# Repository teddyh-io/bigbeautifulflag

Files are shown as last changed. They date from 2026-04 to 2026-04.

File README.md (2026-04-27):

# Truth Social Flagpole

A physical installation that raises an American flag when
[@realDonaldTrump](https://truthsocial.com/@realDonaldTrump) has gone too
long without posting on Truth Social, and lowers it again every time he posts.

## Behaviour

- Poll Truth Social every minute (configurable).
- Flag rises 10% for every 30 minutes of silence, capping at 100%
  (i.e. fully raised after 5 h 30 m of no new posts).
- Any new post drops the flag back to 0%.
- A 64x32 RGB matrix scrolls the body of the latest post.
- When a new post is detected the matrix flashes a "NEW TRUTH" alert
  (two frames alternating every 200 ms for 5 s) before the new body
  scrolls in.
- Truths with attached media are described via OpenAI's vision API
  (`gpt-4o-mini` by default) and the description is appended after the
  body text (or shown by itself if the truth has no caption). Images
  produce an `Image of …` line; videos produce a `Video of …` line
  generated from the preview thumbnail (or the literal `[Video]` if the
  thumbnail is uninformative). Disabled when `OPENAI_API_KEY` isn't set.
- One HW-069 7-seg displays the current flag % and another counts down the
  seconds until the next 10% step.

## Repo layout

```
arduino/
  flagpole/
    flagpole.ino       # Uno sketch (motor + 2x TM1637)

pi/
  flagpole.py          # main systemd service
  calibrate.py         # standalone interactive calibration over SSH
  dev.py               # fake-post dev / demo mode (no Truth Social)
  matrix.py            # Piomatter + tom-thumb BDF scroller
  arduino.py           # serial protocol wrapper for the Uno
  truth.py             # polling + percent/countdown math
  vision.py            # OpenAI gpt-4o-mini wrapper for caption-less truths
  fonts/
    tom-thumb.bdf      # MIT-licensed 4x6 pixel font
  systemd/
    flagpole.service   # systemd unit (points at /home/teddyh/bigbeautifulflag/pi)
  requirements.txt
  .env.example

TWEET/
  FRAME1.png           # "NEW TRUTH" alert, frame 1 (64x32 RGB)
  FRAME2.png           # "NEW TRUTH" alert, frame 2 (64x32 RGB)
  FRAMES.psd           # Photoshop source for the alert frames

Pulley 3D Print/       # mechanical assets (STL/SLDPRT/SCAD)
README.md
.gitignore
```

Everything above is tracked in git except what `.gitignore` excludes:
`.env` (secrets), `__pycache__/`, `bbf-venv/`, the PIL cache built from the
BDF font on first run, and editor/OS cruft.

## Hardware

```
                                   +-------------------+
                                   |   64x32 RGB LED   |
                                   |   Matrix (HUB75)  |
                                   +---------+---------+
                                             |
                                   +---------+---------+
                                   |  Adafruit RGB     |
                                   |  Matrix Bonnet    |
                                   +---------+---------+
                                             |
                                   +---------+---------+
                                   |   Raspberry Pi 5  |
                                   +---------+---------+
                                             |  USB (serial)
                                             |
                                   +---------+---------+
                                   |   Arduino Uno     |
                                   +----+----+----+----+
                                        |    |    |
                                 H-bridge   TM1637 TM1637
                                        |    |    |
                                     Motor  Seg1  Seg2
                                            (flag %) (countdown)
```

### Arduino Uno pin map

See [arduino/flagpole/flagpole.ino](arduino/flagpole/flagpole.ino).

| Pin | Role |
| --- | --- |
| 9 | Motor H-bridge IN1 (PWM) |
| 10  | Motor H-bridge IN2 (PWM) |
| 2 | Seg1 (HW-069 flag %) CLK |
| 3 | Seg1 (HW-069 flag %) DIO |
| 4 | Seg2 (HW-069 countdown) CLK |
| 5 | Seg2 (HW-069 countdown) DIO |

## Arduino firmware (`arduino/`)

1. Install the [TM1637](https://github.com/avishorp/TM1637) library by
   Avishay Orpaz via the Arduino IDE Library Manager.
2. Open `arduino/flagpole/flagpole.ino`, select the Uno + its serial port,
   and upload.
3. The firmware keeps both 7-seg modules showing dashes until the Pi sends
   its first `P` / `T` command.

Calibration data lives in the Uno's EEPROM so it survives reboots and
firmware re-flashes (EEPROM layout is preserved from the original sketch).

## Pi setup (`pi/`)

Target: Raspberry Pi 5 running Raspberry Pi OS Bookworm 64-bit.

This repo is expected to be cloned at `/home/teddyh/bigbeautifulflag/` with
a virtualenv named `bbf-venv/` inside the `pi/` subfolder. If you put it
somewhere else (or name the venv differently), edit
[`pi/systemd/flagpole.service`](pi/systemd/flagpole.service) to match before
installing the service unit.

1. Clone this repo to `/home/teddyh/bigbeautifulflag` (so the Python code
   lives at `/home/teddyh/bigbeautifulflag/pi`).
2. Create the virtualenv **inside `pi/`** and install deps:

   ```bash
   cd ~/bigbeautifulflag/pi
   python3 -m venv bbf-venv
   bbf-venv/bin/pip install -r requirements.txt
   ```

   Piomatter on Pi 5 is a separate wheel; if `pip` can't find it, follow the
   [Adafruit Pi 5 Piomatter guide](https://learn.adafruit.com/rgb-matrix-panels-with-raspberry-pi-5).

3. Wire the Adafruit RGB Matrix Bonnet onto the Pi's 40-pin header and plug
   in the 64x32 HUB75 panel. Power the panel from its own 5V supply.
4. Plug the Arduino Uno into the Pi over USB (typically appears as
   `/dev/ttyACM0`).

## Calibration

Run this once to set the motor's LOW/HIGH endpoints. The Uno persists the
result in EEPROM, so you only redo it after mechanical changes.

```bash
# First run (before the service is installed) — nothing to stop.
cd ~/bigbeautifulflag/pi
bbf-venv/bin/python calibrate.py --port /dev/ttyACM0
```

After the systemd unit is installed, the service owns the serial port
exclusively, so stop it first and start it again when done:

```bash
sudo systemctl stop flagpole.service
cd ~/bigbeautifulflag/pi
bbf-venv/bin/python calibrate.py --port /dev/ttyACM0
sudo systemctl start flagpole.service
```

Keys:

| Key | Action |
| --- | --- |
| ↑ / ↓ | Fine jog (100 ms) |
| W / S | Coarse jog (1 s) |
| L | Mark the LOW endpoint (0%) |
| H | Mark the HIGH endpoint (100%) |
| R | Erase calibration from EEPROM |
| ? | Print Arduino status |
| 0–9 | Goto 0%, 10%, … 90% (once calibrated) |
| Q / Esc | Quit |

## Dev / demo mode

[`pi/dev.py`](pi/dev.py) runs the same motor + matrix + countdown pipeline
as the real service, but takes fake posts from stdin instead of polling
Truth Social. Useful for demoing the rig or debugging hardware without
waiting for @realdonaldtrump to post.

Like calibration, it owns the serial port and the matrix exclusively, so
stop the service first:

```bash
sudo systemctl stop flagpole.service
cd ~/bigbeautifulflag/pi
bbf-venv/bin/python dev.py
# ... type fake posts, age them, etc ...
sudo systemctl start flagpole.service
```

Stdin commands (also shown on startup):

| Input | Action |
| --- | --- |
| `<any text>` | Post `<any text>` at t=now. Flag drops to 0%, NEW TRUTH alert plays, body scrolls. |
| `post <body>` | Same as above, explicit form. |
| `<truth url>` | Pull a real post by URL (e.g. `https://truthsocial.com/@realDonaldTrump/116428386907912654`) and inject it as a fresh truth. Image-only posts get the same OpenAI vision description as the live service. |
| `age <dur>` | Rewind the last post by `<dur>` (e.g. `30s`, `45m`, `2h`, `5h30m`). Flag steps up accordingly within a second. |
| `state` / `?` | Print current percent, countdown, and age of the last post. |
| `help` / `h` | Reprint the banner. |
| `quit` / `q` | Exit (Ctrl-C or EOF also work). |

For typing fake bodies you don't need any credentials, but URL-paste and
the vision fallback both call the upstream APIs:

- Truth Social fetch uses `TRUTHSOCIAL_TOKEN` (or `TRUTHSOCIAL_USERNAME`
  + `TRUTHSOCIAL_PASSWORD`) — same env vars as the main service.
- The image-only vision fallback uses `OPENAI_API_KEY`. Without it,
  image-only posts just scroll `(no post)` instead of a description.

`dev.py` automatically loads `/etc/flagpole.env` (the same file
`flagpole.service` uses via `EnvironmentFile=`), so on the Pi the same
secrets you already configured for the systemd service are picked up
without any extra steps. A developer-local `.env` next to the script (or
anywhere up the cwd) takes precedence over `/etc/flagpole.env` if you
want to override anything for testing.

`ARDUINO_PORT` and `LOG_LEVEL` are honored as in the main service.

## systemd

Install the service so the flagpole starts on boot and restarts on crash.

```bash
cd ~/bigbeautifulflag

# Secrets (not tracked in git)
sudo cp pi/.env.example /etc/flagpole.env
sudo chmod 600 /etc/flagpole.env
sudo $EDITOR /etc/flagpole.env    # fill in TRUTHSOCIAL_USERNAME/PASSWORD

# Service unit
sudo cp pi/systemd/flagpole.service /etc/systemd/system/flagpole.service
sudo systemctl daemon-reload
sudo systemctl enable --now flagpole.service
journalctl -u flagpole.service -f
```

Useful service commands once it's installed:

```bash
sudo systemctl stop    flagpole.service   # stop (e.g. before calibrating)
sudo systemctl start   flagpole.service   # start again
sudo systemctl restart flagpole.service   # after editing code or the unit file
sudo systemctl status  flagpole.service   # quick health check
journalctl -u flagpole.service -n 100     # recent logs
```

The unit runs as `root` because Piomatter needs raw PIO access on the Pi 5.
If you prefer a non-root user, grant `cap_sys_rawio+ep` to the python
binary and change the `User=` line in `pi/systemd/flagpole.service`.

## Configuration

All configurable via environment variables (see [pi/.env.example](pi/.env.example)):

| Var | Default | Notes |
| --- | --- | --- |
| `ARDUINO_PORT` | `/dev/ttyACM0` | USB-serial device for the Uno |
| `TRUTH_HANDLE` | `realdonaldtrump` | Account to watch |
| `POLL_INTERVAL` | `60` | Seconds between Truth Social fetches |
| `TRUTHSOCIAL_USERNAME` | — (required) | Or set `TRUTHSOCIAL_TOKEN` instead |
| `TRUTHSOCIAL_PASSWORD` | — (required) | |
| `TRUTHSOCIAL_TOKEN` | — | Bearer token alternative |
| `OPENAI_API_KEY` | — | Optional. Enables vision description of caption-less image/video truths. |
| `OPENAI_MODEL` | `gpt-4o-mini` | Vision model used for the description call. |
| `LOG_LEVEL` | `INFO` | Any `logging` level name |

## Serial protocol (Pi → Uno)

9600 baud, newline-terminated, ASCII:

| Command | Meaning |
| --- | --- |
| `G<n>` | Move motor to n% (0–100) |
| `P<n>` | Show n on Seg1 flag display (`-1` blanks it) |
| `T<n>` | Start countdown of n seconds on Seg2 (`-1` blanks it)  |
| `U`/`D` | Fine jog up/down |
| `UU`/`DD` | Coarse jog up/down |
| `L`/`H` | Mark LOW / HIGH calibration endpoints |
| `R` | Reset calibration |
| `S` | Print `STATUS:` line |
| `?` | Print help |

The Uno's countdown ticks locally from the last `T` command, so the Pi only
needs to resend when the target changes (in practice, once per
`POLL_INTERVAL`).

## Font

[`pi/fonts/tom-thumb.bdf`](pi/fonts/tom-thumb.bdf) is the MIT-licensed
*Fixed4x6* (tom-thumb) bitmap font by Brian Swetland. It's converted to
PIL's native `.pil`/`.pbm` cache at first run (both gitignored); delete
those files if you ever replace the BDF.

## NEW TRUTH alert frames

[`TWEET/FRAME1.png`](TWEET/FRAME1.png) and
[`TWEET/FRAME2.png`](TWEET/FRAME2.png) are the two 64x32 RGB frames that
alternate every 200 ms for 5 seconds whenever a new post is detected, just
before the body scrolls in.  Replace them with any other pair of 64x32
PNGs to customise the alert — they're loaded once at service start. If the
files are missing the service still runs, it just skips the animation.

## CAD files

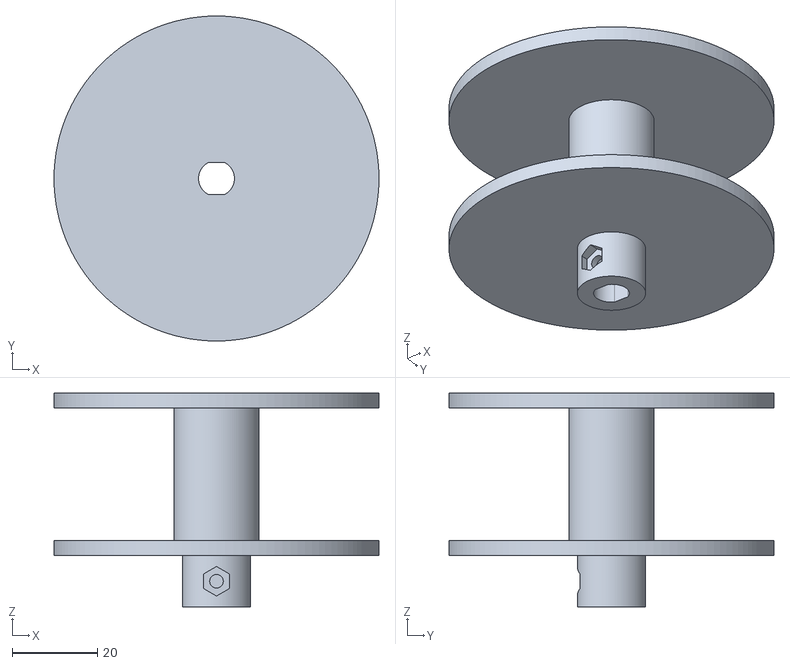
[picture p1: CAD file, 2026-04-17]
Pulley 3D Print/combined_pulley_v4.stl
76.2 x 76.2 x 50.1

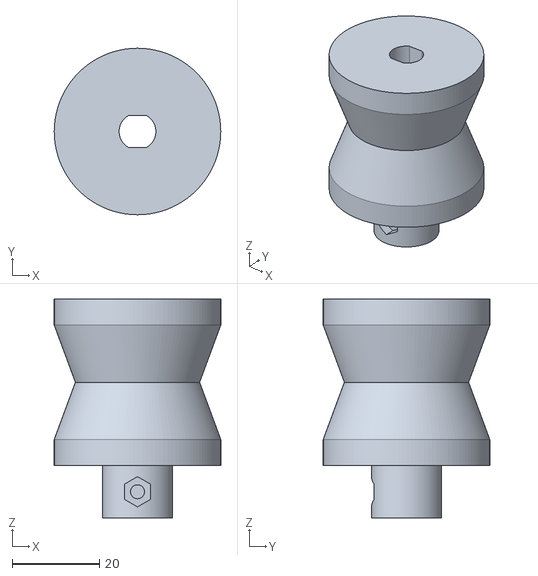
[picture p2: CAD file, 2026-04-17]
Pulley 3D Print/combined_pulley_adapter.stl
38.1 x 38.1 x 50.1

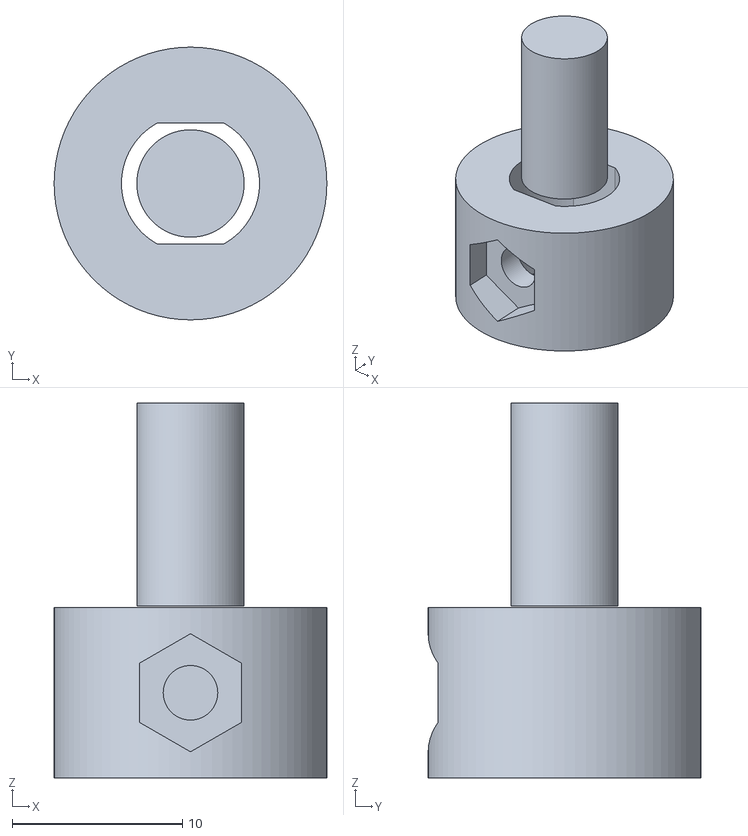
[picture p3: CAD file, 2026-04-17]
Pulley 3D Print/motor_pulley_adapter.stl
16.0 x 16.0 x 22.0

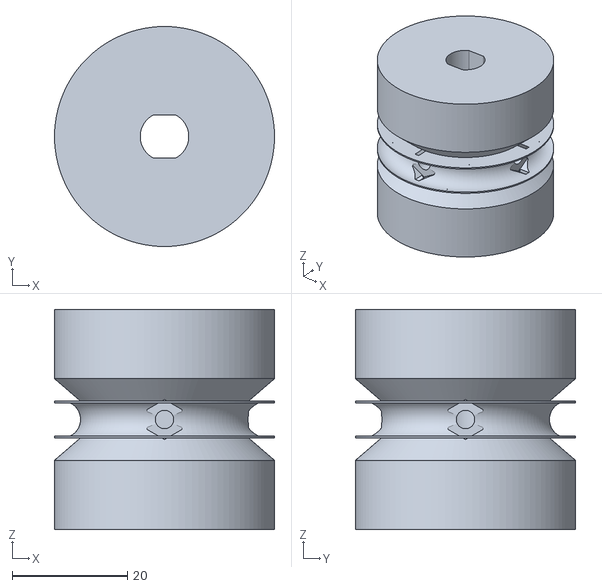
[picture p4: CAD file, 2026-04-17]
Pulley 3D Print/pulley_with_adapter.stl
38.1 x 38.1 x 38.1

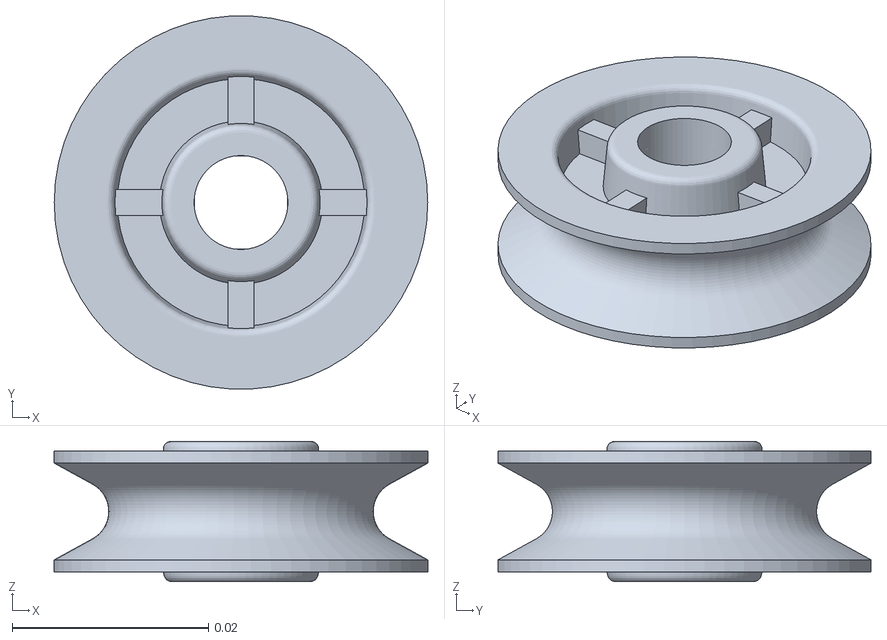
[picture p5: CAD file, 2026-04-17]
Pulley 3D Print/Pulley for Wire Rope 1-4 250 lbs Nylon.stl
0.0381 x 0.038 x 0.0143

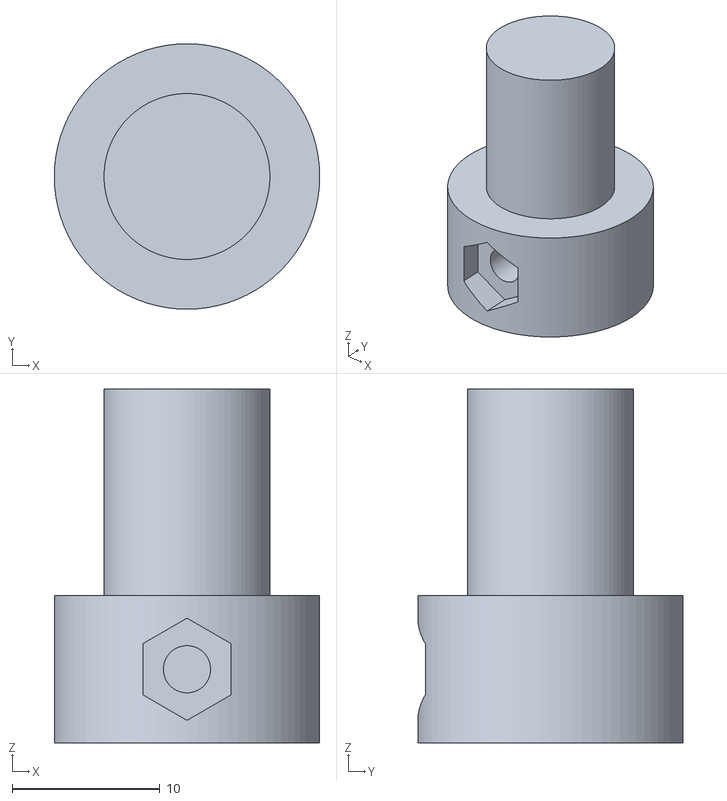
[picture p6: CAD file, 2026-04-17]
Pulley 3D Print/motor_pulley_adapterv3.stl
18.0 x 18.0 x 24.0

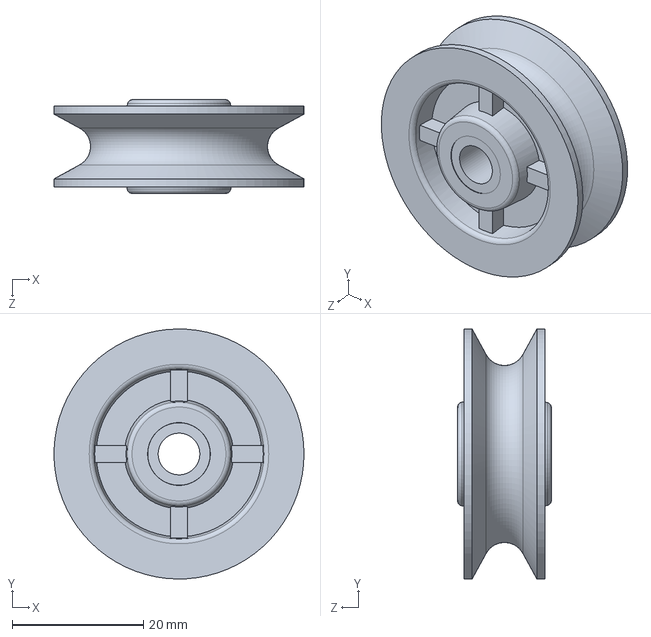
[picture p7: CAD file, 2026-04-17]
Pulley 3D Print/Pulley for Wire Rope 1-4 Rope Diameter 250 lbs Capacity Nylon.SLDPRT
38.1 x 38.1 x 14.3 mm

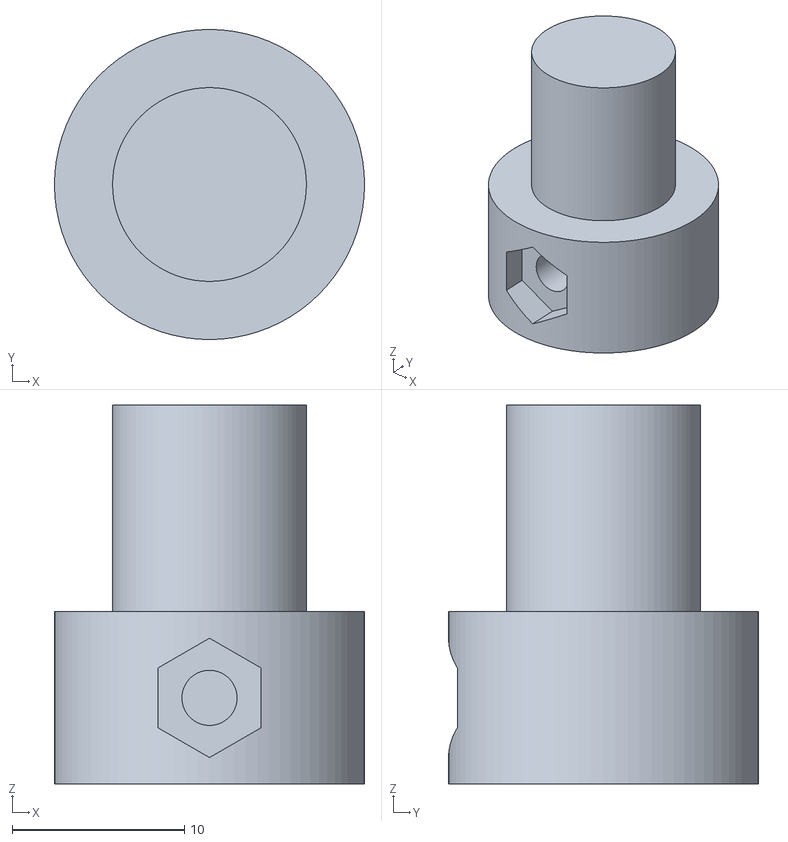
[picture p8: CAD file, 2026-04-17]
Pulley 3D Print/motor_pulley_adapterv2.stl
18.0 x 18.0 x 22.0

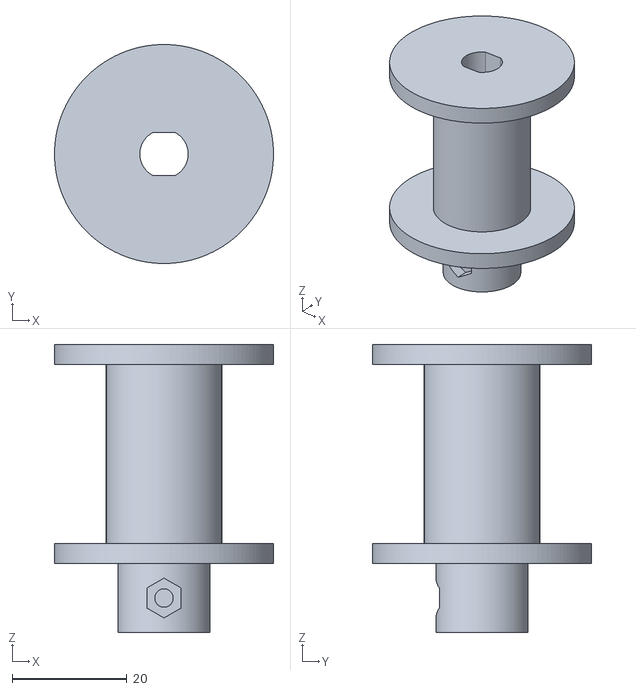
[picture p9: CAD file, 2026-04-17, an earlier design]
Pulley 3D Print/combined_pulley_v3.stl
38.1 x 38.1 x 50.1

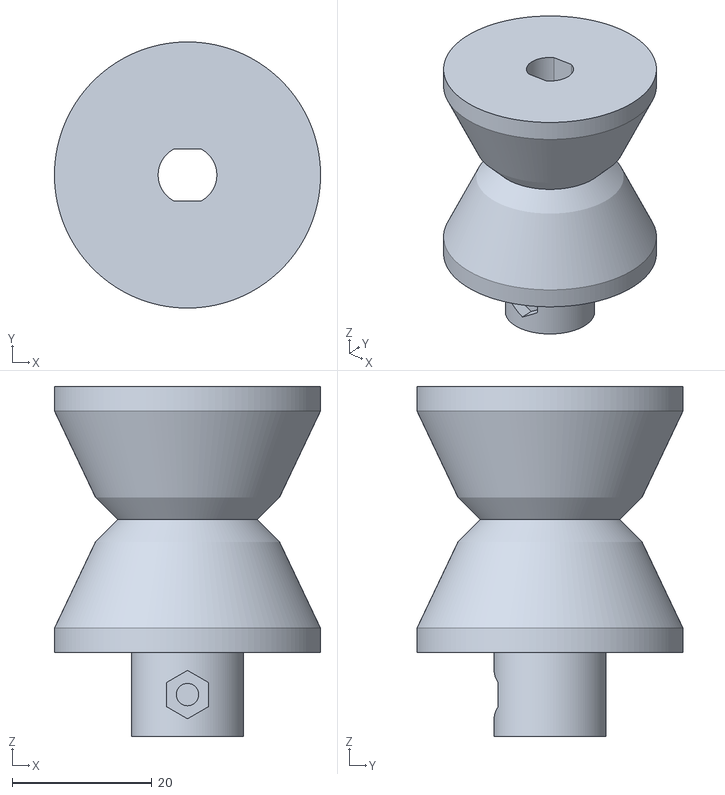
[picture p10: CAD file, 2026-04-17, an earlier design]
Pulley 3D Print/combined_pulley_v2.stl
38.1 x 38.1 x 50.1

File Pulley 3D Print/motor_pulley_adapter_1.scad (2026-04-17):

// Motor-to-Pulley Stepped Adapter
// Bottom: 8mm D-shaped bore (7mm flat) fits over motor shaft
// Top: 11.25mm stub inserts into pulley bore (measured 11.35mm)
// Set screw hole to lock onto motor shaft

// === PARAMETERS (adjust to tune fit) ===

// Motor shaft dimensions (measured: 7mm flat-to-flat)
shaft_dia = 8.4;          // ~8mm round side + 0.4mm clearance for 3D print
d_flat = 7.4;             // 7mm D-flat + 0.4mm clearance (was too tight at 6.9mm)
shaft_depth = 10;         // How deep the shaft inserts into adapter (mm)

// Pulley stub dimensions (measured: 11.35mm bore)
stub_dia = 11.25;         // Slightly under 11.35mm for snug press fit
stub_length = 14;         // How far stub inserts into pulley bore

// Collar (main body) dimensions
collar_dia = 18;          // Outer diameter of the collar section (wider than 11.25mm stub)
collar_height = shaft_depth; // Same as shaft bore depth

// Set screw
set_screw_dia = 3.2;      // M3 set screw hole (tap or use self-tapping)
set_screw_nut_dia = 6.0;  // M3 nut trap width (across flats)
set_screw_nut_depth = 2.5; // M3 nut trap depth

// === RESOLUTION ===
$fn = 80;

// === MODULES ===

// D-shaped bore (8mm round with 7mm flat)
module d_shaft_bore(diameter, flat_width, height) {
    intersection() {
        cylinder(d=diameter, h=height);
        translate([-(diameter/2), -(flat_width/2), 0])
            cube([diameter, flat_width, height]);
    }
}

// === MAIN ASSEMBLY ===
difference() {
    union() {
        // Bottom collar section
        cylinder(d=collar_dia, h=collar_height);
        
        // Top stub that inserts into pulley
        translate([0, 0, collar_height])
            cylinder(d=stub_dia, h=stub_length);
    }
    
    // D-shaped bore from bottom (motor shaft hole)
    translate([0, 0, -0.1])
        d_shaft_bore(shaft_dia, d_flat, shaft_depth + 0.2);
    
    // Set screw hole through collar wall (radial, hits the D-flat)
    // Positioned at mid-height of collar, pointing toward the flat
    translate([0, -(collar_dia/2 + 1), collar_height/2])
        rotate([-90, 0, 0])
            cylinder(d=set_screw_dia, h=collar_dia/2 + 2);
    
    // M3 nut trap on outside of set screw hole
    translate([0, -(collar_dia/2), collar_height/2])
        rotate([-90, 30, 0])
            cylinder(d=set_screw_nut_dia / cos(30), h=set_screw_nut_depth, $fn=6);
}

// === PRINT NOTES ===
// Print with stub pointing UP
// Material: PETG or PLA+ recommended for strength
// Layer height: 0.15-0.2mm for good bore accuracy
// Infill: 80-100%
// No supports needed
// 
// Assembly:
// 1. Slide D-bore onto motor shaft (may need light sanding)
// 2. Insert M3 set screw through nut trap to lock onto shaft
// 3. Press pulley onto the stub
//
// If fit is too loose/tight, adjust clearance values above
// and reprint. D-shaft tolerance is the most critical dimension.

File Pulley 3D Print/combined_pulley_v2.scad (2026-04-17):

// Combined Pulley + Motor Shaft Adapter (Single Part)
// Profile matches McMaster-Carr 9466T75 wire rope pulley
// Modified: 1.5" total width, deep V-groove for 1/4" rope
// D-bore for BRINGSMART A58SW31ZY motor shaft built in

$fn = 120;

// === PULLEY DIMENSIONS ===
pulley_od       = 38.1;     // 1.5" outer diameter
pulley_r        = pulley_od / 2; // 19.05mm radius
pulley_width    = 38.1;     // 1.5" total width (user requested)

// Groove profile
// The V-groove should be deep like the McMaster original
// Rope sits at the bottom of the V
rope_dia        = 6.35;     // 1/4" rope
groove_bottom_r = 10;       // Radius at bottom of V-groove (where rope sits)
groove_round_r  = rope_dia / 2; // Rounded bottom to cradle rope

// Flanges - thin lips at full OD to retain rope
flange_thickness = 3.5;     // Thin flanges at the outer edge

// === MOTOR SHAFT BORE (D-shape) ===
shaft_dia       = 8.4;      // Round side + clearance
d_flat          = 7.4;      // D-flat + clearance

// === SET SCREW ===
set_screw_dia   = 3.2;      // M3 through-hole
nut_width       = 6.0;      // M3 nut across flats
nut_depth       = 2.5;      // M3 nut trap depth

// === HUB ===
hub_od          = 16;        // Hub outer diameter
hub_length      = 12;        // Hub extends behind pulley for shaft grip

// === DERIVED ===
half_width      = pulley_width / 2;

// === MODULES ===

// D-shaped bore
module d_shaft_bore(diameter, flat_width, height) {
    intersection() {
        cylinder(d=diameter, h=height);
        translate([-(diameter/2), -(flat_width/2), 0])
            cube([diameter, flat_width, height]);
    }
}

// 2D pulley cross-section profile for rotate_extrude
// This defines the shape in the XY plane (X = radius from center, Y = width)
// rotate_extrude spins this around the Y axis (which becomes the Z axis)
module pulley_cross_section() {
    // Build the profile as a polygon
    // Going clockwise from inner bottom-left
    
    // Key points:
    // Inner bore area connects to groove bottom via V-walls to flanges at OD
    
    hull_points = [
        // Inner edge (will be bored out anyway, just needs to be < groove_bottom_r)
        [0, 0],                                          // bottom-left (axis, left face)
        [0, pulley_width],                               // top-left (axis, right face)
        
        // Right flange (outer edge, full OD)
        [pulley_r, pulley_width],                        // top-right outer
        [pulley_r, pulley_width - flange_thickness],     // top-right inner lip
        
        // V-groove right wall slopes down to groove bottom
        [groove_bottom_r + groove_round_r, half_width + groove_round_r],  // right side of groove curve
        
        // Groove bottom (rounded for rope)
        [groove_bottom_r, half_width],                   // very bottom of groove
        
        // V-groove left wall slopes up
        [groove_bottom_r + groove_round_r, half_width - groove_round_r],  // left side of groove curve
        
        // Left flange
        [pulley_r, flange_thickness],                    // bottom-left inner lip
        [pulley_r, 0],                                   // bottom-left outer
    ];
    
    polygon(points = hull_points);
}

// Smoother groove with actual rounded bottom
module pulley_body() {
    rotate_extrude(convexity=10)
        pulley_cross_section();
}

// === MAIN PART ===
difference() {
    union() {
        // Pulley body
        pulley_body();
        
        // Hub extending behind the pulley
        translate([0, 0, -hub_length])
            cylinder(d=hub_od, h=hub_length);
    }
    
    // D-shaped bore all the way through
    translate([0, 0, -hub_length - 0.1])
        d_shaft_bore(shaft_dia, d_flat, hub_length + pulley_width + 0.2);
    
    // Set screw hole (radial, through the hub)
    translate([0, -(hub_od/2 + 1), -hub_length/2])
        rotate([-90, 0, 0])
            cylinder(d=set_screw_dia, h=hub_od/2 + 2);
    
    // M3 nut trap
    translate([0, -(hub_od/2), -hub_length/2])
        rotate([-90, 30, 0])
            cylinder(d=nut_width / cos(30), h=nut_depth, $fn=6);
}

// === PRINT NOTES ===
// Print with hub pointing UP, flat flange on bed
// Material: PETG recommended
// Infill: 80-100%
// Layer height: 0.15-0.2mm
// Walls: 4+ perimeters
// Supports: Not needed (V-groove overhang is gradual)
//
// The groove is now deep like the original McMaster pulley -
// rope sits well below the OD with thin retaining flanges.

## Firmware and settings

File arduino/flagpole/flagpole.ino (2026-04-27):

// Truth Social Flagpole — Arduino Uno firmware
//
// Drives:
//   * H-bridge flag motor on pins 9 (IN1) / 10 (IN2)
//   * HW-069 (TM1637) 4-digit 7-seg #1 on pins 2 (CLK) / 3 (DIO)  — flag percent
//   * HW-069 (TM1637) 4-digit 7-seg #2 on pins 4 (CLK) / 5 (DIO)  — countdown MM:SS
//
// Required library (install via Arduino IDE Library Manager):
//   "TM1637" by Avishay Orpaz   (header: TM1637Display.h)
//
// Serial protocol (9600 baud, newline-terminated, from Raspberry Pi 5):
//   U / D / UU / DD   jog motor (calibration)
//   L / H             mark low / high calibration endpoints
//   R                 reset calibration
//   S / ?             status / help
//   G<pct>            move motor to pct (0-100)
//   P<pct>            set percent display (Seg1)
//   T<secs>           start countdown on Seg2; -1 blanks it
//
// EEPROM layout is preserved from the previous firmware so existing
// calibration survives an upgrade.

#include <EEPROM.h>
#include <TM1637Display.h>

// ── Motor ─────────────────────────────────────────────────────────────────
#define MOTOR_IN1 9
#define MOTOR_IN2 10

// PWM speeds for positioning. Gravity assists downward motion,
// so DOWN runs at half speed to keep travel distances consistent.
// Changing these invalidates calibration — recalibrate after any change.
#define MOTOR_SPEED_UP   100
#define MOTOR_SPEED_DOWN 50

#define JOG_FINE_MS   100
#define JOG_COARSE_MS 1000

// ── 7-segment displays ────────────────────────────────────────────────────
#define SEG1_CLK 4
#define SEG1_DIO 5
#define SEG2_CLK 2
#define SEG2_DIO 3
#define SEG_BRIGHTNESS 4   // 0..7

TM1637Display seg1(SEG1_CLK, SEG1_DIO);
TM1637Display seg2(SEG2_CLK, SEG2_DIO);

const uint8_t SEG_DASHES[4] = {0x40, 0x40, 0x40, 0x40};
const uint8_t SEG_BLANK[4]  = {0x00, 0x00, 0x00, 0x00};

// ── EEPROM ────────────────────────────────────────────────────────────────
#define EEPROM_MAGIC_ADDR 0
#define EEPROM_RANGE_ADDR 1   // 4 bytes (long)
#define EEPROM_POS_ADDR   5   // 4 bytes (long)
#define EEPROM_MAGIC_VAL  0xCA

// ── State ─────────────────────────────────────────────────────────────────
long range_ms    = 0;
long position_ms = 0;
bool calibrated  = false;
bool low_set     = false;

int  pct_display    = -1;    // -1 => blank
long countdown_sec  = -1;    // -1 => blank, 0 => hold at 00:00
unsigned long last_tick_ms = 0;
bool colon_on = true;

// ── Motor primitives ──────────────────────────────────────────────────────
void stopMotor() {
  analogWrite(MOTOR_IN1, 0);
  analogWrite(MOTOR_IN2, 0);
  digitalWrite(MOTOR_IN1, LOW);
  digitalWrite(MOTOR_IN2, LOW);
}

void runMotorUp(long ms) {
  if (ms <= 0) return;
  stopMotor();
  delay(20);
  digitalWrite(MOTOR_IN1, LOW);
  analogWrite(MOTOR_IN2, MOTOR_SPEED_UP);
  delay(ms);
  stopMotor();
}

void runMotorDown(long ms) {
  if (ms <= 0) return;
  stopMotor();
  delay(20);
  analogWrite(MOTOR_IN1, MOTOR_SPEED_DOWN);
  digitalWrite(MOTOR_IN2, LOW);
  delay(ms);
  stopMotor();
}

// ── EEPROM helpers ────────────────────────────────────────────────────────
void saveCalibration() {
  EEPROM.update(EEPROM_MAGIC_ADDR, EEPROM_MAGIC_VAL);
  EEPROM.put(EEPROM_RANGE_ADDR, range_ms);
  EEPROM.put(EEPROM_POS_ADDR, position_ms);
}

void savePosition() {
  EEPROM.put(EEPROM_POS_ADDR, position_ms);
}

void loadCalibration() {
  if (EEPROM.read(EEPROM_MAGIC_ADDR) != EEPROM_MAGIC_VAL) return;
  EEPROM.get(EEPROM_RANGE_ADDR, range_ms);
  EEPROM.get(EEPROM_POS_ADDR, position_ms);
  if (range_ms > 0) {
    calibrated = true;
    low_set = true;
    Serial.print(F("CAL:loaded,range="));
    Serial.print(range_ms);
    Serial.print(F("ms,pos="));
    Serial.print(position_ms);
    Serial.print(F("ms,pct="));
    Serial.println(position_ms * 100 / range_ms);
  }
}

// ── Motor commands ────────────────────────────────────────────────────────
void jogUp(long step_ms) {
  if (calibrated && position_ms >= range_ms) {
    Serial.println(F("ERR:At upper limit"));
    return;
  }
  long actual = step_ms;
  if (calibrated) {
    actual = min(step_ms, range_ms - position_ms);
  }
  runMotorUp(actual);
  position_ms += actual;
  Serial.print(F("OK:Jog up "));
  Serial.print(actual);
  Serial.print(F("ms,pos="));
  Serial.println(position_ms);
}

void jogDown(long step_ms) {
  if (calibrated && position_ms <= 0) {
    Serial.println(F("ERR:At lower limit"));
    return;
  }
  long actual = step_ms;
  if (calibrated) {
    actual = min(step_ms, position_ms);
  }
  runMotorDown(actual);
  position_ms -= actual;
  Serial.print(F("OK:Jog down "));
  Serial.print(actual);
  Serial.print(F("ms,pos="));
  Serial.println(position_ms);
}

void setLow() {
  position_ms = 0;
  low_set = true;
  calibrated = false;
  Serial.println(F("OK:Low set. Jog up to high, press H."));
}

void setHigh() {
  if (!low_set) {
    Serial.println(F("ERR:Set low first (L)"));
    return;
  }
  if (position_ms <= 0) {
    Serial.println(F("ERR:Jog up from low first"));
    return;
  }
  range_ms = position_ms;
  calibrated = true;
  saveCalibration();
  Serial.print(F("OK:High set. Range="));
  Serial.print(range_ms);
  Serial.println(F("ms. Saved."));
}

void gotoPercent(int pct) {
  if (!calibrated) {
    Serial.println(F("ERR:Not calibrated"));
    return;
  }
  pct = constrain(pct, 0, 100);
  long target = (long)pct * range_ms / 100;
  long diff = target - position_ms;

  Serial.print(F("OK:Moving to "));
  Serial.print(pct);
  Serial.print(F("% (delta="));
  Serial.print(diff);
  Serial.println(F("ms)"));

  if (diff > 0) {
    runMotorUp(diff);
  } else if (diff < 0) {
    runMotorDown(-diff);
  }

  position_ms = target;
  savePosition();
  Serial.print(F("POS:"));
  Serial.println(pct);
}

void printStatus() {
  Serial.print(F("STATUS:cal="));
  Serial.print(calibrated ? F("yes") : F("no"));
  Serial.print(F(",range="));
  Serial.print(range_ms);
  Serial.print(F("ms,pos="));
  Serial.print(position_ms);
  Serial.print(F("ms,pct="));
  if (calibrated && range_ms > 0) {
    Serial.println(position_ms * 100 / range_ms);
  } else {
    Serial.println(F("N/A"));
  }
}

void printHelp() {
  Serial.println(F("Commands:"));
  Serial.println(F("  U/D    Fine jog up/down"));
  Serial.println(F("  UU/DD  Coarse jog up/down"));
  Serial.println(F("  L/H    Mark low/high calibration endpoints"));
  Serial.println(F("  G<n>   Go to n% (0-100)"));
  Serial.println(F("  P<n>   Show n% on Seg1 (-1 blanks)"));
  Serial.println(F("  T<n>   Start countdown of n seconds on Seg2 (-1 blanks)"));
  Serial.println(F("  S      Status"));
  Serial.println(F("  R      Reset calibration"));
  Serial.println(F("  ?      Help"));
}

// ── 7-seg rendering ───────────────────────────────────────────────────────
void renderPercent() {
  if (pct_display < 0) {
    seg1.setSegments(SEG_DASHES);
  } else {
    // Right-aligned with no leading zeros.
    seg1.showNumberDec(pct_display, false);
  }
}

void renderCountdown() {
  if (countdown_sec < 0) {
    seg2.setSegments(SEG_DASHES);
    return;
  }
  long total = countdown_sec;
  if (total > 5999) total = 5999;  // clamp to 99:59
  int mm = total / 60;
  int ss = total % 60;
  int value = mm * 100 + ss;
  // Dot bit 0x40 on digit index 1 lights the colon between digits 2 and 3.
  uint8_t dots = colon_on ? 0x40 : 0x00;
  seg2.showNumberDecEx(value, dots, true);
}

void tickCountdown() {
  unsigned long now = millis();
  if (now - last_tick_ms < 1000) return;
  last_tick_ms += 1000;
  colon_on = !colon_on;
  if (countdown_sec > 0) countdown_sec--;
  renderCountdown();
}

// ── Setup / loop ──────────────────────────────────────────────────────────
void setup() {
  Serial.begin(9600);
  pinMode(MOTOR_IN1, OUTPUT);
  pinMode(MOTOR_IN2, OUTPUT);
  stopMotor();

  seg1.setBrightness(SEG_BRIGHTNESS);
  seg2.setBrightness(SEG_BRIGHTNESS);
  seg1.setSegments(SEG_BLANK);
  seg2.setSegments(SEG_BLANK);
  renderPercent();
  renderCountdown();

  loadCalibration();
  last_tick_ms = millis();
  Serial.println(F("READY"));
}

void loop() {
  tickCountdown();

  if (!Serial.available()) return;

  String input = Serial.readStringUntil('\n');
  input.trim();
  if (input.length() == 0) return;

  if      (input == "U")  jogUp(JOG_FINE_MS);
  else if (input == "D")  jogDown(JOG_FINE_MS);
  else if (input == "UU") jogUp(JOG_COARSE_MS);
  else if (input == "DD") jogDown(JOG_COARSE_MS);
  else if (input == "L")  setLow();
  else if (input == "H")  setHigh();
  else if (input == "S")  printStatus();
  else if (input == "?")  printHelp();
  else if (input == "R") {
    EEPROM.update(EEPROM_MAGIC_ADDR, 0);
    calibrated = false;
    range_ms = 0;
    position_ms = 0;
    low_set = false;
    Serial.println(F("OK:Calibration cleared"));
  }
  else if (input.startsWith("G") || input.startsWith("g")) {
    gotoPercent(input.substring(1).toInt());
  }
  else if (input.startsWith("P") || input.startsWith("p")) {
    int v = input.substring(1).toInt();
    pct_display = (v < 0) ? -1 : constrain(v, 0, 9999);
    renderPercent();
    Serial.print(F("OK:P="));
    Serial.println(pct_display);
  }
  else if (input.startsWith("T") || input.startsWith("t")) {
    long v = input.substring(1).toInt();
    countdown_sec = (v < 0) ? -1 : v;
    last_tick_ms = millis();
    colon_on = true;
    renderCountdown();
    Serial.print(F("OK:T="));
    Serial.println(countdown_sec);
  }
  else {
    Serial.println(F("ERR:Unknown. Send ? for help."));
  }
}

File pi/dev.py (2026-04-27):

#!/usr/bin/env python3
"""Truth Social flagpole DEV / DEMO MODE.

Runs the same motor + matrix + countdown pipeline as :mod:`flagpole`, but
instead of polling Truth Social, takes fake posts from stdin so you can
demo or debug the rig without waiting for @realdonaldtrump to post.

Usage::

    sudo systemctl stop flagpole.service   # release /dev/ttyACM0 + matrix
    cd ~/bigbeautifulflag/pi
    bbf-venv/bin/python dev.py
    # ... type fake posts, age them, etc ...
    sudo systemctl start flagpole.service  # when done
"""

from __future__ import annotations

import argparse
import logging
import os
import re
import signal
import sys
import threading
from datetime import datetime, timedelta, timezone

from dotenv import load_dotenv

from arduino import Arduino
from flagpole import _PollState, _tick_loop
from matrix import MatrixScroller, clean_body
from truth import compute
from vision import describe_media


log = logging.getLogger("dev")

# Same path systemd uses (EnvironmentFile= in pi/systemd/flagpole.service).
# Loaded automatically so URL-paste / vision auth "just works" on the Pi
# without having to copy secrets next to the script.
SYSTEM_ENV_FILE = "/etc/flagpole.env"


BANNER = """\
──────────────────────────────────────
         FLAGPOLE DEV MODE
──────────────────────────────────────
  <text>       Post <text> now (resets flag, plays NEW TRUTH)
  post <body>  Same as above, explicit form
  <truth url>  Pull a real post by URL and inject it as a new truth
               e.g. https://truthsocial.com/@realDonaldTrump/1234...
               (any post with media gets an OpenAI vision description
               appended, same as the live service)
  age <dur>    Rewind last post by <dur> — e.g. 30s, 45m, 2h, 5h30m
  state / ?    Print current percent, countdown, last post age
  help / h     Show this banner
  quit / q     Exit (Ctrl-C or EOF also work)
──────────────────────────────────────
"""


_DUR_RE = re.compile(r"^(?:(\d+)h)?(?:(\d+)m)?(?:(\d+)s)?$")
_POST_URL_RE = re.compile(
    r"^https?://(?:www\.)?truthsocial\.com/@([^/\s]+)/(\d+)(?:[/?#]|$)",
    re.IGNORECASE,
)
_DEFAULT_HANDLE = "realdonaldtrump"


def _parse_duration(s: str) -> timedelta | None:
    """Parse '30s' / '45m' / '2h' / '5h30m' style strings. Returns None if invalid."""
    m = _DUR_RE.match(s.strip())
    if not m or not any(m.groups()):
        return None
    h, mi, se = (int(x) if x else 0 for x in m.groups())
    return timedelta(hours=h, minutes=mi, seconds=se)


def _inject_post(
    scroller: MatrixScroller,
    state: _PollState,
    body: str,
    *,
    alert: bool,
) -> None:
    """Push a fake post into the shared state + matrix."""
    scroller.set_body(body, alert=alert)
    with state.lock:
        state.post_time = datetime.now(timezone.utc)


def _print_state(state: _PollState) -> None:
    with state.lock:
        pt = state.post_time
    if pt is None:
        print("no post yet", flush=True)
        return
    now = datetime.now(timezone.utc)
    age = (now - pt).total_seconds()
    pct, countdown = compute(now, pt)
    print(
        f"post age={age:.0f}s  pct={pct}%  "
        f"countdown={'—' if countdown < 0 else f'{countdown}s'}",
        flush=True,
    )


def _parse_post_url(line: str) -> tuple[str, str] | None:
    """Return ``(handle, post_id)`` for a Truth Social post URL, else ``None``."""
    m = _POST_URL_RE.match(line.strip())
    if not m:
        return None
    return m.group(1), m.group(2)


def _fetch_status_by_id(post_id: str) -> dict | None:
    """Fetch a single Truth Social status by ID via truthbrush.

    truthbrush has no public single-status helper, so we hit the underlying
    Mastodon-compatible endpoint through ``Api._get``. ``TRUTHSOCIAL_TOKEN``
    in the env (loaded by truthbrush itself at import) is enough to auth;
    we fall back to a no-op ``lookup()`` to force a username/password login
    when only those are set.
    """
    try:
        from truthbrush.api import Api
    except ImportError as exc:
        log.warning("truth: truthbrush not installed: %s", exc)
        return None

    api = Api()
    if api.auth_id is None:
        try:
            api.lookup(_DEFAULT_HANDLE)
        except Exception as exc:
            log.warning("truth: login failed: %s", exc)
            return None

    try:
        status = api._get(f"/v1/statuses/{post_id}")
    except Exception as exc:
        log.warning("truth: GET /v1/statuses/%s failed: %s", post_id, exc)
        return None

    if not isinstance(status, dict) or "content" not in status:
        log.warning("truth: unexpected response for %s: %r", post_id, status)
        return None
    return status


def _resolve_display_body(status: dict) -> str:
    """Pick the matrix body for a fetched status.

    Mirrors the behaviour of ``flagpole._fetch_loop``: if the post has
    media attached, we run an OpenAI vision description and append it
    after the body text (or use it alone when there's no caption). If
    vision is unavailable, we fall through to the original body.
    """
    body = status.get("content", "") or ""

    media_url: str | None = None
    media_kind: str | None = None
    for att in status.get("media_attachments") or []:
        att_type = att.get("type")
        if att_type == "image" and att.get("url"):
            media_url = att["url"]
            media_kind = "image"
            break
        if att_type in ("video", "gifv") and att.get("preview_url"):
            media_url = att["preview_url"]
            media_kind = "video"
            break

    if not media_url:
        return body

    description = describe_media(media_url, kind=media_kind or "image")
    if not description:
        return body
    if clean_body(body):
        return f"{body}\n{description}"
    return description
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
